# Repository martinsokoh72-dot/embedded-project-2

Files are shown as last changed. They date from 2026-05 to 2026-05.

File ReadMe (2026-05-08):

STM32L432 Advanced PC Fan Speed Controller with Overspeed Alarm
Author: Martins Osemudiamen Okoh
TU Dublin ID: A00047170
Course: Embedded Systems Project – EENG1030

Project Description
This embedded system project implements a real-time, closed-loop motor speed monitoring and control system using an STM32L432KC microcontroller. The system reads rotational speed from a quadrature encoder for user input and a tachometer for fan feedback. It controls the fan speed via PWM output, provides visual feedback using an LED, and activates an audible buzzer alarm when the fan exceeds a safe speed threshold of 3500 RPM. A serial debug interface and an SPI display provide real-time status information.

The video showcase of this project can be viewed via: https://youtu.be/aQIbt7y0xQ4?si=APt8LlkEA8uwMtla
A techncial report for this project can be found in this repository: /Technical Report.pdf
The schematic design was performed using KIcad in this repository: /embeeded_project_design.kicad_sch
The main source code file for this project can be found in this repository directory: /source code/src/main.c

Aim & Objectives
Aim: Design and implementation of an advanced PC fan speed controller using an STM32L432KC microcontroller with an overspeed alarm.

Objectives:

1) Schematic design of the PC fan speed controller.
2) Software implementation.
3) Hardware implementation.
4) Testing / Debugging (software and hardware).
5) Documentation.

Hardware Requirements
Components List
1) STM32L432KC microcontroller board (e.g., Nucleo-L432KC)
2) 12V PC Fan with 4-wire connection (PWM control & Tachometer output)
3) Quadrature rotary encoder
4) 1.8" TFT SPI LCD (ST7735S)
5) LED (visual status indicator)
6) Buzzer (audible alarm)
7) Push button (for tachometer input)
8) 330 Ohm resistor
9) Breadboard and connecting wires
10) 12V DC Bench Power Supply
11) USB-to-UART converter / USB Cable (for serial debugging)

System Pin Connections
    Component	        Signal	              STM32L432 Pin	Function
1)  Rotary Encoder      CLK	                  PA0	TIM2_CH1 (Encoder Input)
                        DT	                  PB3	TIM2_CH2 (Encoder Input)
                        VCC                   3.3V	Power
                        GND	                  GND	Ground
    
2)  PC Fan	            PWM (Blue)	          PA6	TIM16_CH1 (Speed Control)
                        Tachometer (Green)	  PB4	EXTI4 (Speed Feedback)
                        GND (Black)	          GND	Ground
                        +12V (Yellow)	        12V Supply	Power
    
3)  LED Indicator	    Anode	                PB5	Overspeed Status
                        Cathode	              GND (via 330Ω)	
    
4)  Buzzer	            Positive	            PB6	Audible Alarm
                        Negative	            GND	
    
5)  LCD Screen (SPI)    LCD	                  3.3v
                        SCL	                  PA5	SPI1_SCK
                        SDA	                  PA7	SPI1_MOSI
                        CS	                  PA4	Chip Select
                        RESET	                PB0	Reset
                        DC	                  PB1	Data/Command
                        VCC	                  3.3V	Power
                        GND	                  GND	Ground
    
6)  Serial Debug	    TX	                  PA2	USART2_TX
                        RX	                  PA15	USART2_RX

Features
1) Encoder-based Speed Control: A quadrature encoder connected to TIM2 (Mode 3) provides precise user input for setting the fan speed.
2) PWM Generation: Timer 16 produces a 25 kHz PWM signal on PA6, with a duty cycle adjustable from 0% to 100% based on the encoder position.
3) Tachometer Speed Calculation: Measures actual fan RPM by counting tachometer pulses (2 pulses/rev) on PB4 over a 0.1333-second interval.
4) Overspeed Detection & Alarm: Triggers an audiovisual alarm when the RPM exceeds 3500.
5) Visual Alarm: LED (PB5) turns OFF (normally ON when speed is safe).
6) Audible Alarm: Buzzer (PB6) generates a 500 Hz square wave.
7) Real-Time Monitoring: Outputs encoder value, PWM duty, and RPM to a serial console for debugging.
8) SPI Display: Shows current encoder position and fan RPM on a 1.8" TFT LCD.

        Key System Parameters
    Parameter	                      Value
1)  System Clock	                  80 MHz
2)  PWM Frequency	                  25 kHz
3)  PWM Resolution	                  3200 steps (ARR = 3199)
4)  Encoder Count Range	              0 - 159 (ARR = 159)
5)  RPM Safe Threshold	              3500 RPM
6)  Buzzer Tone Frequency	          500 Hz
7)  Buzzer Timer Interrupt Rate	      1000 Hz (1 ms)
8)  Main Loop Update Rate	          10 Hz (100 ms delay)

Register Configuration Summary
Timer 2 (Encoder)
1) Mode: Quadrature encoder mode 3 (counts on both edges of TI1 and TI2)
2) Auto-reload (ARR): 159 (0-159 count range)
3) Inputs: PA0 (TI1) and PB3 (TI2) as capture inputs (Alternate Function 1)

Timer 16 (PWM for Fan Speed)
1) Prescaler (PSC): 0
2) Auto-reload (ARR): 3199 (results in 80 MHz / 3200 = 25 kHz)
3) Pulse (CCR1): 1600 (default 50% duty cycle)
4) Output: PA6 (Alternate Function 14)
5) Break and Dead-Time (BDTR): MOE bit set (required for PWM output)

Timer 6 (Buzzer Tone)
1) Prescaler (PSC): 7999 (divides 80 MHz to 10 kHz)
2) Auto-reload (ARR): 9 (results in 10 kHz / 10 = 1 kHz update events)
3) Interrupt: Toggles PB6 on each interrupt, producing a 500 Hz square wave when active.

External Interrupt (EXTI4 for Tachometer)
1) Pin: PB4
2) Trigger: Falling edge
3) Action: Increments pulse_count variable on each fan pulse (2 pulses/rev)

Software Structure & Operation
Main Loop (10 Hz Update Rate)
Read encoder counter (TIM2->CNT) as the desired speed position.
Scale the encoder value (0-159) to a PWM duty cycle (0-3199) and update TIM16->CCR1.
Safely copy the interrupt-driven pulse_count (with interrupts temporarily disabled).

Calculate speed in Hz and RPM:
speed_hz = pulse_count / pulse_per_rev (pulse_per_rev = 2)
speed_rpm = speed_hz × 450 (The factor 450 is derived from a 0.1333s measurement interval: 60 / 0.1333 = 450).

Check overspeed condition:
If RPM <= 3500: Turn LED ON, set playing = 0 (buzzer off).
If RPM > 3500: Turn LED OFF, set playing = 1 (buzzer on).

Output status string via serial (Encoder, PWM, RPM, Buzzer State).
Update SPI display with current encoder position and RPM.
Delay for 100 ms and repeat.

Interrupt Handlers
TIM6_DAC_IRQHandler: Runs at 1 kHz. If playing == 1, toggles PB6 to generate a 500 Hz tone. If playing == 0, ensures PB6 is LOW.

EXTI4_IRQHandler: Runs on every falling edge from the fan's tachometer pin (PB4). Increments the volatile pulse_count variable.

Building and Flashing
Prerequisites
ARM GCC toolchain (arm-none-eabi-gcc)
STM32CubeProgrammer or OpenOCD
ST-Link debugger (built into Nucleo boards)

Setup & Build Instructions
Clone the repository and navigate to the project directory.
Connect the STM32L432 Nucleo board to your PC via USB.
Run make to build the project and generate the binary file.
Run make flash to program the binary onto the microcontroller using ST-Link.

Serial Output Examples
Initialization Verification:

MODER PA6: 2
AFR PA6: 14
TIM16 CR1: 129
TIM16 CCER: 1
TIM16 BDTR: 32768
TIM16 ARR: 3199
TIM16 CCR1: 1600
Runtime Monitoring:

ENC: 45, CCR1: 905, RPM: 1250, buzz: 0
ENC: 78, CCR1: 1568, RPM: 2150, buzz: 0
ENC: 120, CCR1: 2415, RPM: 3300, buzz: 0
ENC: 155, CCR1: 3118, RPM: 4250, buzz: 1   ← Overspeed!

Troubleshooting
Symptom	Likely Cause	Fix
No PWM output	MOE bit not set in TIM16 BDTR	Ensure TIM16->BDTR = 0x8000 in initTimer16().
Encoder not counting	Wrong alternate function for pins	Verify PA0 and PB3 are configured as Alternate Function 1 (AF1).
Buzzer always silent	TIM6 interrupt disabled	Check NVIC ISER1 bit 22 (IRQ 54) is enabled.
LED always off	Constant overspeed condition or GPIO error	Verify the speed_rpm calculation and PB5 mode.
Fan not spinning at 100%	PWM frequency mismatch	Ensure TIM16 ARR=3199 for 25kHz, as required by the 4-wire fan spec.
Display blank	SPI initialization failure or power	Check display power (3.3V) and SPI connections (PA5, PA7, PA4, etc.).

Safety Notes
Hearing Protection: The buzzer produces a 500 Hz tone at full volume during overspeed. Avoid prolonged exposure during testing.

Voltages: The system uses a 12V supply for the fan. Ensure all connections are secure to prevent short circuits.

Fan Safety: Keep objects away from the fan blades while the system is powered.

Current Limits: The LED is current-limited by a 330Ω resistor. Do not connect the LED without a current-limiting resistor.

Files in Project
File	Description
main.c	Main program, peripheral initialization, and main loop.
display.h/c	SPI display driver for the ST7735S LCD.
eeng1030_lib.h	Course library with utilities for GPIO, delays, serial, etc.
Makefile	Build configuration for the ARM GCC toolchain.

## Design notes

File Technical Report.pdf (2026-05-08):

# Technical Report

# Embedded System Project: Advanced PC FAN speed controller with over-speed alarm. Author: Martins Osemudiamen

# Okoh. TU Dublin ID: A00047170

Table of Content I. AIm | 1 II. Objective | 1 III. Design | 1 IV. Components | 2 V. Software Code | 9 VI. Testing | 20 VII. Conlusion | 24 VIII. Reference | 25

Table of Table

I. Table 1: STM32L432KC | 2
II. Table 2: PIN connection | 2
III. Table 3: Button | 3
IV. Table 4: LED | 3
V. Table 5: Resistor | 3
VI. Table 6: Rotary Encoder | 4
VII. Table 7: PIN connection | 4
VIII. Table 8: LCD Screen | 5
IX. Table 9: PIN connection | 5
X. Table 10: Buzzer | 5
XI. Table 11: PC FAN | 6
XII. Table 12: 4-wire PinOut | 6
XIII. Table 13: USB Cable | 7
XIV. Table 14: Breadboard | 7
XV. Table 15: Connecting wires | 7
XVI. Table 16: Power Supply | 8
Tables of Figures
I. Figure 1: Ciricuit Design of PC fan controller using KICad 10.0. | 1
II. Figure 2: Declaration of functions and addition of necessary files and libraries. | 9
III. Figure 3: Declaration of global variables. | 9
IV. Figure 4: Main function of the software implementation part 1. | 10
V. Figure 5: Main function of the software implementation part 2. | 11
VI. Figure 6: Main function of the software implementation part 3. | 11
VII. Figure 7: Main function of the software implementation part 4. | 12
VIII. Figure 8: Setup Function. | 13
IX. Figure 9: delay , Pull Up resistor and Pinmode. | 14
X. Figure 10: Timer 2. | 15
XI. Figure 11: Timer 16. | 16
XII. Figure 12: Timer 6. | 16
XIII. Figure 13: Timer 6 interrupt . | 17
XIV. Figure 14: Function of installing delay. | 17
XV. Figure 15: Function to enable pull-up resistor. | 17
XVI. Figure 16: Function for PIN mode selection. | 18
XVII. Figure 17: Function for initializing clock. | 18
XVIII. Figure 18: Function of initializing serial communication and pin definition. | 18
XIX. Figure 19: Function for writing via serial communication. | 19
XX. Figure 20: Function for write via serial communication to terminal display. | 19
XXI. Figure 21: Function to handle interrupt to counting the speed pulse. | 19
XXII.Figure 22: Function for milliseconds counting and delays. | 19
XXIII. Figure 23: Hardware implementation of bread board. | 20
XXIV. Figure 24: Power supply. | 21
XXV. Figure 25: Output result 1 on terminal. | 21
XXVI. Figure 26: Output result 2 on terminal. | 21
XXVII. Figure 27: Fan output speed signal 1 viewed on oscilloscope. | 22
XXVIII. Figure 28: PC fan Assemble with LED ON and Screen. | 22
XXIX. Figure 29: Output result 2 on terminal. | 23
XXX.Figure 30: Fan output speed signal 2 viewed on oscilloscope. | 23
XXXI. Figure 31: PC fan Assemble with LED OFF, Buzzer toggling and Screen . | 24

Aim: Design and implementation of a Advanced PC fan speed controller using STM32L432KC microcontroller with overspeed alarm. Objective:

1. Schematic design of the PC fan speed controller. 2. Software implementation. 3. Hardware implementation. 4. Testing / Debugging. 5. Documentation. Design:

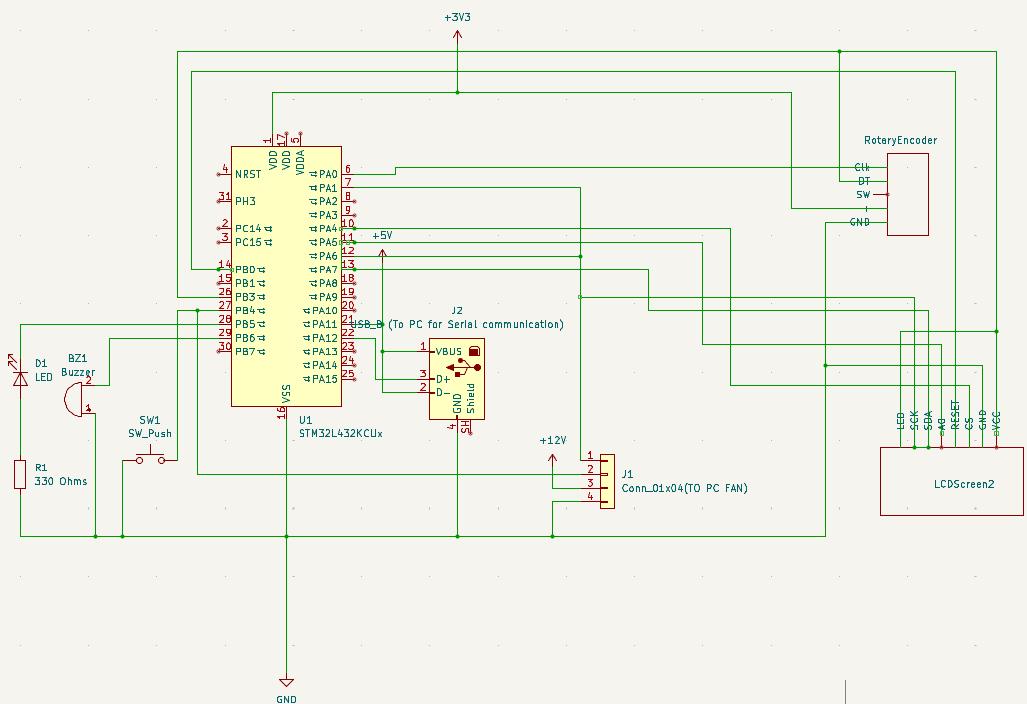
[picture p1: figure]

Figure 1: Ciricuit Design of PC fan controller using KICad 10.0.

In the Figure 1 above, the design comprises of STM32L432KC microcontroller, a push button, an LED,330 Ohms resistor, Rotary Encoder, LCD Screen, Buzzer, PC fan 4 wire connector, a

USB cable component for serial communication, voltage supplies of 3.3 and 12 voltages, connecting wires, breadboard and a ground.

Components:

1) STM32L432KC Microcontroller:

Table 1: STM32L432KC
Specification | Detail
Manufacturer | STMicroelectronics
Core | ARM Cortex-M4F (with FPU)
Max frequency | 80 MHz
Flash memory | 256 KB
SRAM | 64 KB
Operating voltage | 1.71V – 3.6V
Package | 32-pin QFN
Key peripherals | GPIO, TIM2, TIM6, TIM16, USART, SPI, EXTI, NVIC

Component Role: Central processing unit. Runs the main control loop, reads encoder and push button inputs, generates PWM for the fan, controls the LED and buzzer, communicates with the LCD via SPI, and outputs debug data over USB serial. It also serve as a 3.3 volt power supply for the circuit [1). Connection: The Pin connection is as in Table 2. Table 2: PIN connection

Pin | Direction | Function
PA0 | Input | TIM2_CH1 – Encoder CLK (AF1)
PA2 | Output | USART2_TX – Serial transmit (AF7)
PA5 | Output | SPI1_SCK – Display clock
PA6 | Output | TIM16_CH1 – PWM fan control (AF14)
PA7 | Output | SPI1_MOSI – Display data
PA15 | Input | USART2_RX – Serial receive (AF3)
PB3 | Input | TIM2_CH2 – Encoder DT (AF1)
PB4 | Input | EXTI4 – Tachometer pulse input (falling edge)
PB5 | Output | GPIO – LED overspeed indicator
PB6 | Output | GPIO – Buzzer tone output (toggled by TIM6)

All peripherals are clocked through the internal PLL configured to 80 MHz at startup in initClocks(). SysTick is configured to interrupt every 1 ms to provide the delay_ms() timebase [2].

2) Push Down Button:
Table 3: Button
Specification | Detail
Type | Tactile momentary switch
Number of pins | 2 connected internally
Actuation Force | 100 - 300gf
Contact resistance | < 100 mΩ
Operating life | 10,000 – 100,000 cycles

Component Role: Provides user input for controlling the system (e.g., starting/stopping the fan, resetting the system, or toggling display modes). In this project, it may serve as the tachometer pulse input or a manual override switch [3]. Connection: Connected to PB4 with internal pull-up enabled. When pressed, the pin reads

LOW (0V); when released, pull-up keeps it HIGH (3.3V). Falling edge triggers an external interrupt. 3) Light Emitting Diode (LED) :

Table 4: LED
Specification | Detail
Type | Standard 5mm or SMD LED
Color | Green
Forward voltage (Vf) | 2.8V – 3.2V (green)
Forward current (If) | 10 – 20 mA
Viewing angle | 1000 – 5000 mcd 30° – 60° Luminous intensity

Component Role: Visual status indicator. Illuminates when the fan speed is within safe limits (≤ 3500 RPM) and turns off during over speed conditions [4]. Connection: Anode connected to PB5 through a 330Ω current-limiting resistor; cathode

connected to ground. 4) 330 Ohm resistor:

Table 5: Resistor
Specification | Detail
Resistance | 330 Ω ±5%
Power rating | 0.25W (1/4W)
Type | Carbon film or metal film
Color code | Orange – Orange – Brown – Gold

Component Role: Current-limiting resistor for the LED. 330Ω provides approximately 4 mA current, ensuring safe operation without exceeding the LED's maximum rating or the microcontroller's GPIO current limit (20 mA per pin) [5]. Connection: Placed in series between PB5 (microcontroller output) and the LED anode.

5) Rotary Encoder:

Table 6: Rotary Encoder
Specification | Detail
Type | Incremental quadrature encoder
Pulses per revolution (PPR) | 2 (as defined in code: #define pulse_per_rev 2)
Output signals | Channel A (CLK), Channel B (DT)
Output type | Open-collector or push-pull
Supply voltage | 3.3V – 5V
Mechanical life | 30,000 – 100,000 cycles
Encoder Count Range | 0 – 159 (set by TIM2 ARR = 159 in code)

Component Role: Provides the primary user input for fan speed control. As the knob is rotated clockwise or counter-clockwise, it generates two out-of-phase square wave signals (CLK and DT) which TIM2 decodes in hardware encoder mode 3 (quadrature). The resulting count value in TIM2->CNT (ranging 0–159) is read in the main loop and scaled to a PWM duty cycle on TIM16, directly controlling fan speed. Rotating fully clockwise produces maximum PWM (100% duty), and fully counter-clockwise produces minimum (0%) [6]. Connection: The Pin connection is as in Table 2. Table 7: PIN connection

Encoder Pin | STM32L432 Pin
CLK | PA0
DT | PB3
VCC | 3.3v
GND | GND
SW | - How it works: PA0 and PB3 are configured in alternate function mode (AF1) to route directly

into TIM2's hardware encoder interface. TIM2 is configured in encoder mode 3 (TIM2- >SMCR = 3), meaning both edges of both channels are counted, giving smooth and accurate

position tracking. The counter wraps between 0 and 159 as set by TIM2->ARR = 159. No software debouncing is required as the hardware timer filters signal noise inherently. Internal pull-ups are not explicitly set for PA0/PB3 as the encoder module typically includes its own pull-up resistors on CLK and DT.

6) LCD Screen (SPI Interface)

Table 8: LCD Screen
Specification | Detail
Type | 1.8" TFT SPI LCD v1.1
Resolution | 128 × 160 pixels
Display Driver IC | ST7735S
Interface | SPI (Serial Peripheral Interface)
Operating voltage | 3.3V
Colour Depth | 16-bit (65,536 colours)
Viewable Area | 1.8 inches diagonal
Pixel Format | RGB565

Component Role: Provides a real-time visual readout of system state to the user. In this project, it displays the current rotary encoder position (pos) and the calculated fan speed (RPM). Text is rendered using printText() and screen regions are cleared between updates using fillRectangle() to prevent display artefacts. Colour coding is used to distinguish data fields — yellow for encoder position, green for RPM [7]. Connection: The Pin connection is as in Table 9. Table 9: PIN connection

Display Pin | STM32L432 Pin
VCC | 3.3v
GND | GND
SCL | PA5
SDA | PA7
RESET | PB0
DC | PB1
CS | PA4
LED | 3.3v

7 ) Buzzer:
Table 10: Buzzer
Specification | Detail
Type | Piezoelectric transducer
Resonant frequency | 500 Hz (typical)
Operating voltage | 3V – 12V
Current consumption | 5 – 15 mA
Sound pressure level | 75 – 85 dB at 10 cm

Component Role: Audible alarm. Activates when the fan speed exceeds 3500 RPM, producing a 500 Hz tone to alert the user of an overspeed condition [8].

Connection: Positive (+) to PB6 (microcontroller output) and Negative (-) to Ground

Drive method: Timer 6 generates a 1000 Hz interrupt that toggles PB6 at 500 Hz when playing = 1, creating a square wave. The buzzer produces sound due to the piezoelectric element vibrating at this frequency . Behavior:

Speed ≤ 3500 RPM: playing = 0 via PB6 LOW I.e silent
Speed > 3500 RPM: playing = 1 via PB6 toggles at 500 Hz I.e audible tone
7) PC FAN with 4-wire connection:

Table 11: PC FAN
Specification | Detail
Type | Brushless DC fan (computer cooling fan)
Wire colors (standard) | Black (GND), Yellow (12V), Green (Tachometer), Blue (PWM control)
Supply voltage | 12V DC
Current draw | 0.1A – 0.5A (typical)
Speed range | 0 – 4000+ RPM

Table 12: 4-wire PinOut
Wire Color | Signal | Function
Black | GND | Ground (0V)
Yellow | +12V | Power supply (12V)
Green | Tachometer | Open-collector output (2 pulses per revolution)
Blue | PWM | Speed control input (25 kHz, 0–100% duty cycle)

Component Role: The main actuator being controlled and monitored. The microcontroller sends a PWM signal to the blue wire to regulate fan speed, and reads tachometer pulses from the green wire to measure actual RPM [9]. Connection:Black (GND) to Common ground, Yellow (12V) to External 12V power supply, Green (Tachometer) to PB4 (EXTI4 interrupt input) – counts speed pulses and Blue (PWM) to

PA6 (TIM16 CH1) – receives 25 kHz PWM signal. How speed is measured: The fan's tachometer output produces 2 pulses per revolution

(open-collector). Each falling edge on PB4 triggers an interrupt, incrementing pulse_count. The main loop calculates speed every 0.1333 seconds. How speed is controlled: The PWM duty cycle on PA6 determines fan speed. The encoder

value (0–159) is scaled to set TIM16->CCR1 (0–3199). Duty cycle range: 0% (fan off) to 100% (maximum speed).

8) USB Cable (serial communication):

Table 13: USB Cable
Specification | Detail
Type | USB C
Length | 0.5m – 1m (typical)
Interface | USB 2.0 full-speed
Purpose | Provides serial communication between STM32 and PC

Component Role: Enables real-time monitoring and debugging. The STM32L432's USART peripheral is connected to the USB port via an onboard USB-to-serial converter (on Nucleo boards or external FTDI adapter). The PC receives debug messages at 9600 baud using a serial terminal (PuTTY, screen, minicom) [10]. Data transmitted are Initialization verification (register values) and Runtime status (encoder value, PWM duty, RPM, buzzer state). Connection: USB cable connects the microcontroller board to a computer. The computer's

serial monitor displays the debug output. 9) Breadboard:

Table 14: Breadboard
Specification | Detail
Type | Solderless breadboard
Size | 400 – 830 tie points (typical)
Contact material | Nickel-plated or tin-plated phosphor bronze
Pitch | 2.54mm (0.1 inch)

Component Role: Prototyping platform for assembling the circuit without soldering. Components and wires are inserted into the breadboard's contact holes, which are

electrically connected in rows and columns. The ground row is used as neural ground connections [11]. 10) Connecting wires:

Table 15: Connecting wires
Specification | Detail
Type | Jumper wires
Gauge | 22 AWG – 26 AWG
Length | 10 cm – 30 cm
Connector type | Dupont (2.54mm pitch)

Component Role: Establish all electrical connections between components on the breadboard [12].

Typical connections include:

i. Microcontroller pins to breadboard power rails
ii. Encoder to microcontroller pins (PA0, PB3, VCC, GND) iii. Push button to PB4 and ground
iv. LED and resistor to PB5 and ground
v. Buzzer to PB6 and ground
vi. LCD to SPI pins, VCC, and GND
vii. Fan tachometer (green) to PB4
viii. Fan PWM (blue) to PA6
ix. Fan ground (black) to common ground
x. Fan 12V (yellow) to 12V supply
xi. 3.3V and GND to breadboard power rails
11) Power Supply:

Table 16: Power Supply
Specification | Detail
Type | Regulated DC Bench Power Supply
Output Voltage | 0 – 30V DC (adjustable)
Output Current | 0 – 5A (adjustable limit)
Input Voltage | 220–240V AC, 50Hz
Output Terminals | Positive (+), Negative (−), Ground (GND)
Accuracy | ±(0.5% to 1%) depending on model
Ripple/Noise | Typically < 10mV

Component Role: The positive terminal (+12V) of the power supply is connected to the fan’s power input wire, while the negative terminal (GND) is connected to the fan ground wire I.e +terminal to Fan VCC (12v) and -terminal to GND [13].

Source Code:

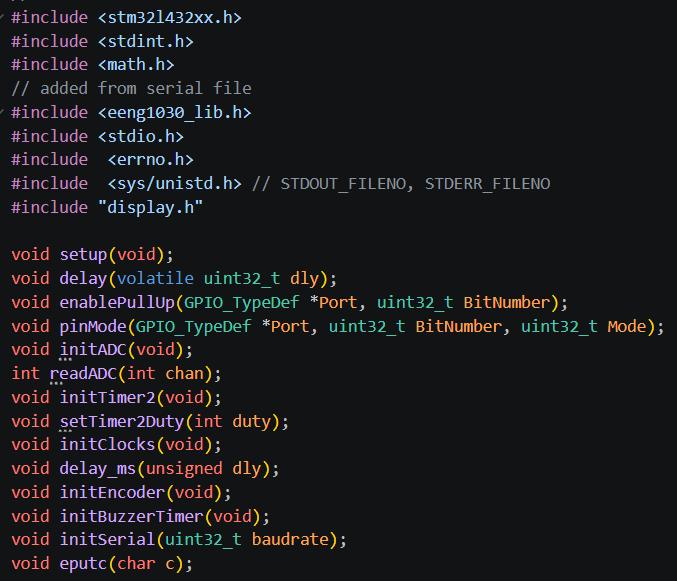
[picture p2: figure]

Figure 2: Declaration of functions and addition of necessary files and libraries. Figure 2 above shows a hardware initialization and utility library for an STM32L432xx

microcontroller (ARM Cortex-M4). It provides core functions for peripheral control, timing, analog reading, PWM generation, encoder interfacing, buzzer control, and serial

communication. The code appears to be part of a larger embedded systems project (likely for a robotics or mechatronics course, given the eeng1030_lib.h reference).

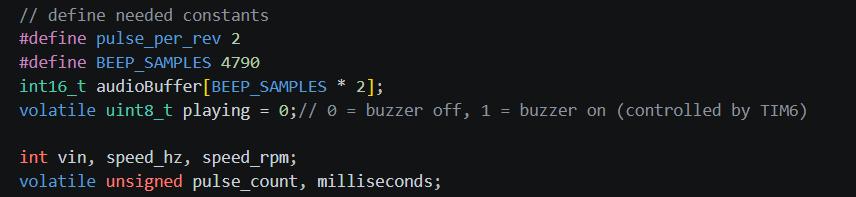
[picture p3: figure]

Figure 3: Declaration of global variables. Figure 3 above shows the constants and variables for motor speed sensing and buzzer audio

playback on an STM32 microcontroller. The constant pulse_per_rev is set to 2, meaning the motor encoder generates two pulses per revolution, while BEEP_SAMPLES defines the audio buffer size as 4790 samples. An int16_t array called audioBuffer allocates twice that many elements (9580 total) to store audio data for buzzer tones, and a volatile uint8_t flag named playing tracks whether the buzzer is active (1) or off (0), with updates controlled by Timer 6 interrupts. Integer variables vin, speed_hz, and speed_rpm hold motor voltage input and speed values in hertz and RPM respectively. Finally, two volatile unsigned variables— pulse_count for counting encoder pulses and milliseconds for system timing—are declared volatile because they are modified inside interrupt service routines but accessed in the main program loop.

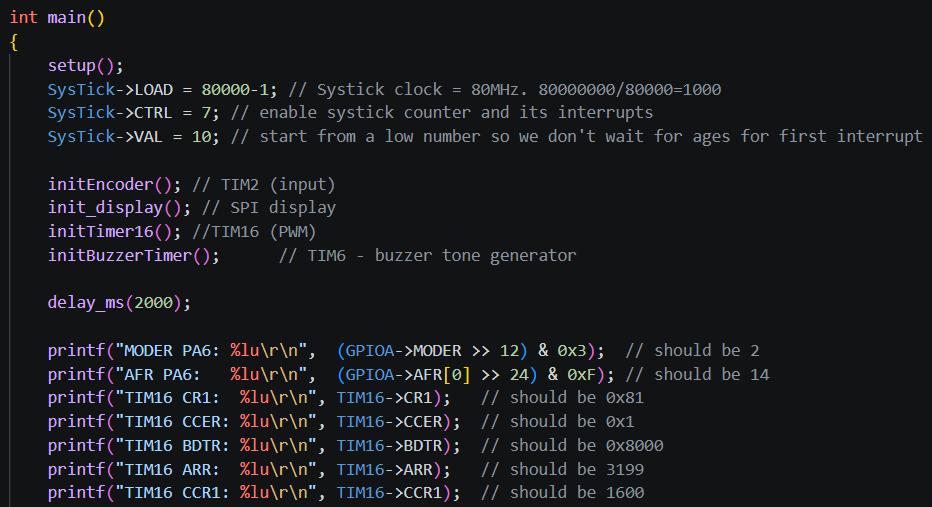
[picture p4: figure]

Figure 4: Main function of the software implementation part 1. This main() function in Figure 4 above initializes the entire embedded system and then

verifies the configuration by printing register values. It begins by calling setup() for basic hardware initialization, then configures the SysTick timer to generate interrupts every 1 millisecond (since an 80 MHz clock with a load value of 80,000 produces exactly 1000 Hz). It initializes the encoder on Timer 2, an SPI display, Timer 16 for PWM output, and Timer 6 for buzzer tone generation. After a 2-second delay to allow everything to stabilize, it prints the current register values for GPIO pin PA6 (checking its mode and alternate function), followed by several Timer 16 registers including CR1 (control), CCER (capture/compare enable), BDTR (break and dead-time), ARR (auto-reload value), and CCR1 (capture/compare value). These print statements serve as diagnostic checks to confirm that Timer 16 was configured correctly—for example, the ARR should be 3199 and CCR1 should be 1600, indicating a 50% duty cycle on the PWM output.

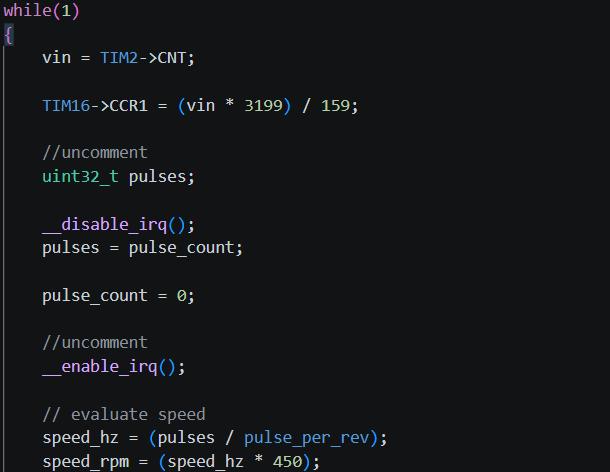
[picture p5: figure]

Figure 5: Main function of the software implementation part 2. Figure 5 above shows continuous loop reads the motor's input voltage from Timer 2's

counter register, scales it by a factor of 3199/159 (approximately 20.12) and writes the result to Timer 16's capture compare register to control a PWM output—likely for motor speed or LED brightness. It then safely copies the volatile pulse_count variable into a local pulses variable by disabling interrupts briefly to prevent corruption during the read, resets pulse_count to zero for the next measurement interval, and re-enables interrupts. Finally, it calculates the motor speed in hertz by dividing the accumulated pulses by pulse_per_rev (which is 2), then converts that to RPM by multiplying by 450—the conversion factor assumes the measurement period is 0.1333 seconds (since 60 seconds divided by 0.1333 equals 450). This loop continuously reads feedback, updates control outputs, and computes rotational speed in real time.

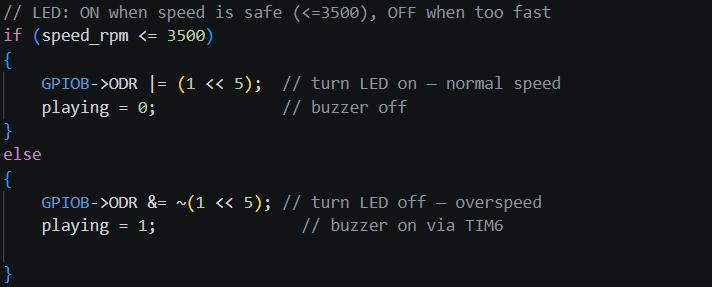
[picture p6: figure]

Figure 6: Main function of the software implementation part 3.

This code implemented in Figure 6 shows a safety monitoring system that controls an LED and buzzer based on motor speed. If speed_rpm is 3500 RPM or less (safe zone), it turns the LED on by setting bit 5 of GPIOB's output data register, and ensures the buzzer is off by setting playing = 0. If the speed exceeds 3500 RPM (overspeed condition), it turns the LED off by clearing bit 5, and activates the buzzer by setting playing = 1, which enables Timer 6 to generate an audible alarm tone. This provides both visual feedback (LED on/off) and audible warning (buzzer) to alert the user when the motor is running too fast.

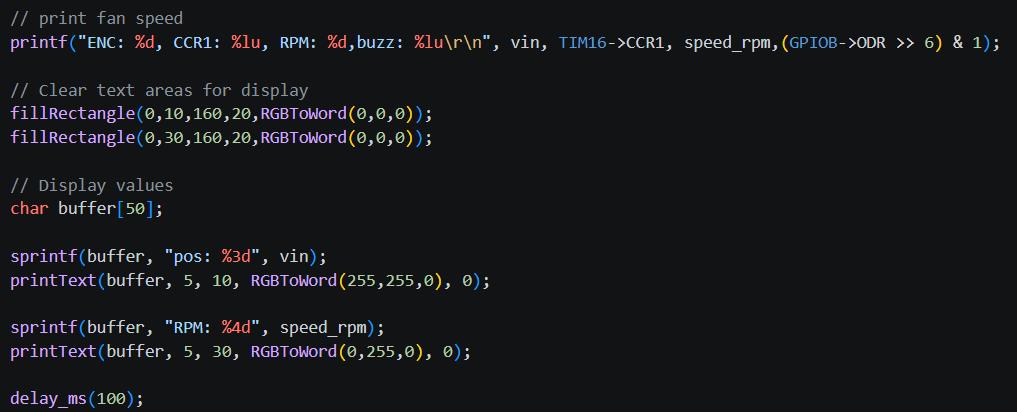
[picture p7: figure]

Figure 7: Main function of the software implementation part 4. This code in Figure 7 handles real-time data output and user interface updates. It first prints

a status line over serial containing the encoder value (vin), the current PWM capture compare register value from Timer 16, the calculated motor speed in RPM, and the buzzer state (extracted from bit 6 of GPIOB's output data register). It then updates an SPI display by clearing two text areas (at Y-positions 10 and 20, and 30 and 40) using black rectangles. The encoder position (vin) is formatted into a string labeled "pos" and displayed in yellow text at the top, while the RPM value is formatted and displayed in green text below. Finally, a 100 millisecond delay sets the loop's update rate to approximately 10 Hz, providing stable, readable updates without overwhelming the system.

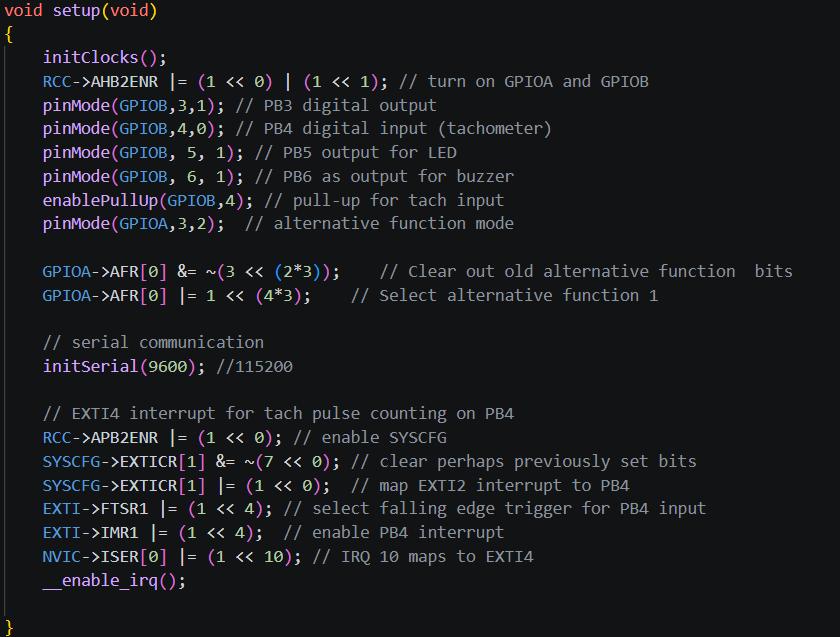
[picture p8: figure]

Figure 8: Setup Function. This setup() function shown in Figure 8 above performs all low-level hardware initialization

for the system. It starts by calling initClocks() to configure system clocks, then enables GPIO ports A and B via the AHB2ENR register. It configures several GPIO pins: PB3 as a digital output, PB4 as a digital input for tachometer sensing (with a pull-up enabled), PB5 as an output for the status LED, and PB6 as an output for the buzzer. Pin PA3 is set to alternative function mode, and its alternate function is configured to AF1 (likely for timer input capture). Serial communication is initialized at 9600 baud for debugging output. The function then

sets up an external interrupt on PB4 to count tachometer pulses: it enables the SYSCFG clock, configures the EXTI to map PB4 to interrupt line 4, selects falling edge triggering, enables the

interrupt in the EXTI controller, and enables the EXTI4 interrupt in the NVIC (IRQ 10). Finally, it globally enables interrupts with __enable_irq(), allowing the tachometer pulse counting to begin.

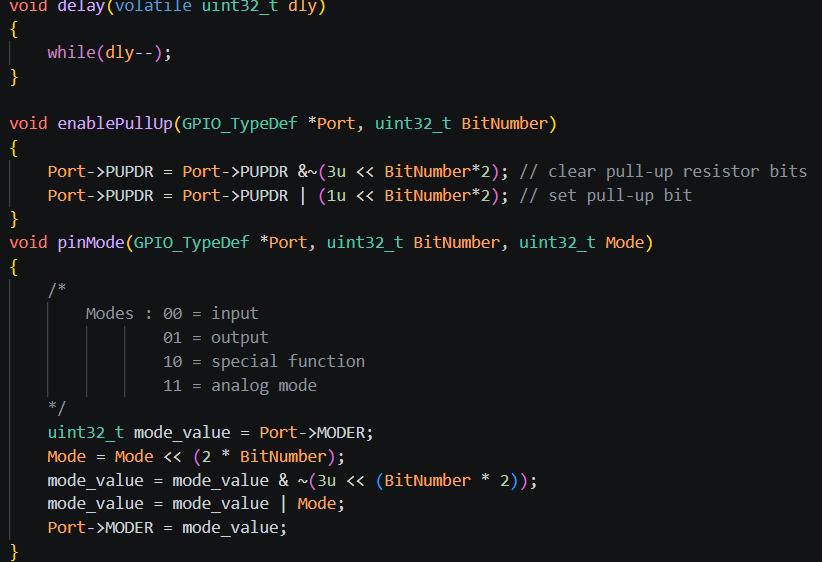
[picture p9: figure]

Figure 9: delay , Pull Up resistor and Pinmode. These three functions shown in Figure 9 above provide basic GPIO control and timing

utilities. delay(volatile uint32_t dly) creates a simple blocking delay by decrementing the input value

in a tight while loop until it reaches zero. The parameter is declared volatile to prevent the
compiler from optimizing away the loop. enablePullUp(GPIO_TypeDef | *Port, | uint32_t | BitNumber) | activates the internal pull-up

resistor on a specified GPIO pin. It clears the two bits controlling the pull configuration for that pin by ANDing with a mask, then sets the lower bit (binary 01) to select pull-up mode. pinMode(GPIO_TypeDef *Port, uint32_t BitNumber, uint32_t Mode) configures the mode of

a GPIO pin by writing to the port's MODER register. The Mode parameter (0=input, 1=output, 2=alternate function, 3=analog) is shifted left by twice the bit number to align with the two

bits that control that pin, then combined into the register after clearing the existing configuration bits for that pin.

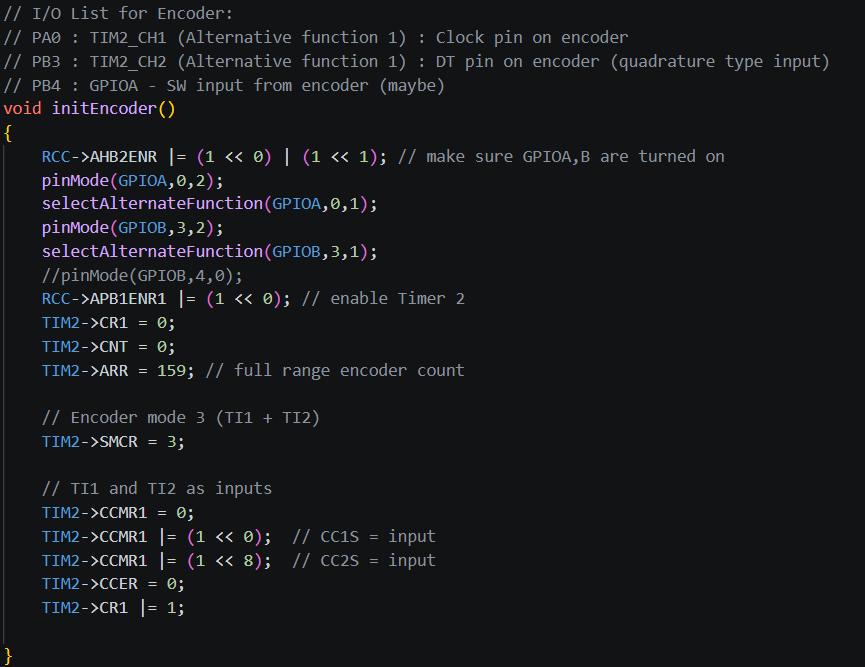
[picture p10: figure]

Figure 10: Timer 2. This initEncoder() function configures Timer 2 shown in Figure 10 above in encoder mode to

read a quadrature rotary encoder. It enables GPIOA and GPIOB clocks, then configures PA0 as TIM2 channel 1 (clock pin) and PB3 as TIM2 channel 2 (DT pin) both in alternate function mode with AF1 selected. Timer 2 is enabled, its counter is reset to zero, and the auto-reload register ARR is set to 159, which limits the count range from 0 to 159. The SMCR register is set to mode 3, which configures the timer to count on both TI1 and TI2 edges (quadrature decoding). The CCMR1 register sets both capture compare channels 1 and 2 as inputs, and CCER is cleared to configure the inputs. Finally, the timer is started by setting bit 0 in CR1. As the encoder rotates, the timer count automatically increments or decrements based on direction, and the value can be read from TIM2->CNT.

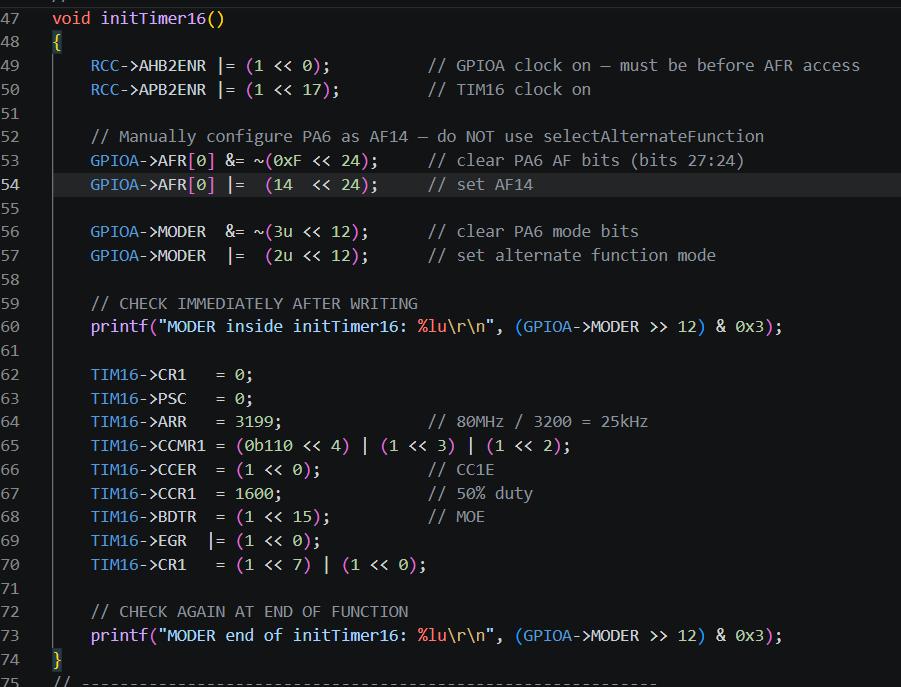
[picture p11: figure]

Figure 11: Timer 16. This initTimer16() function shown in Figure 11 configures Timer 16 to generate a PWM signal

on pin PA6. It enables the GPIOA clock and Timer 16 clock, then manually configures PA6 to use alternate function 14 (AF14), which is the timer output channel for TIM16. The pin mode is set to alternate function. Diagnostic printf statements verify the pin's mode register value immediately after configuration. The timer itself is then set up: prescaler is 0, the auto- reload register ARR is 3199, which with an 80 MHz clock produces a PWM frequency of 25

kHz. The CCMR1 register configures channel 1 for PWM mode 2 (110 binary) with preload enabled, and CCER enables the capture/compare output. CCR1 is set to 1600, giving a 50% duty cycle. The BDTR register's MOE (Main Output Enable) bit is set, which is required for advanced timers to enable PWM output. An update event generates reloads the settings, and CR1 enables auto-reload preload and starts the timer counter.

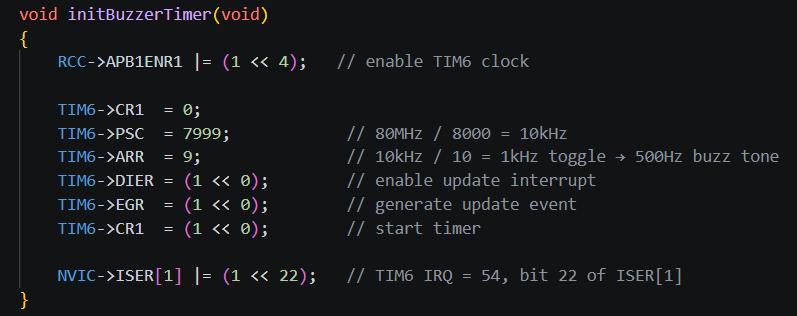
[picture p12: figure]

Figure 12: Timer 6.

This initBuzzerTimer() function shown in Figure 12 above configures Timer 6 to generate an interrupt for producing an audible buzzer tone. It enables the TIM6 clock via the APB1ENR1 register, then sets the prescaler to 7999, which divides the 80 MHz system clock down to 10 kHz. The auto-reload register ARR is set to 9, meaning the timer counts from 0 to 9 and then resets, creating an update event at 1 kHz (since 10 kHz divided by 10 equals 1000 Hz). This triggers an interrupt twice per cycle, allowing the buzzer pin to toggle at 500 Hz, which produces an audible 500 Hz tone. The DIER register enables the update interrupt, an update event is generated to load the prescaler and ARR values, and the timer is started by setting bit 0 in CR1. Finally, the interrupt is enabled in the NVIC at IRQ number 54 (bit 22 in ISER[1]), allowing the buzzer control to be handled in the TIM6 interrupt service routine.

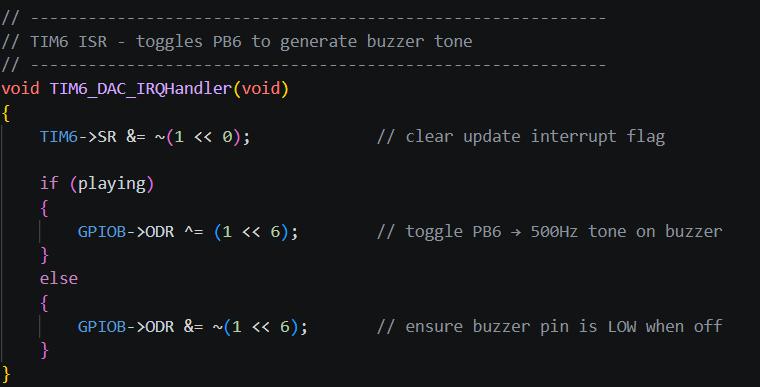
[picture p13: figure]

Figure 13: Timer 6 interrupt . This is the interrupt service routine for Timer 6 shown in Figure 13 which generates the

buzzer tone. When a timer update interrupt occurs, the handler first clears the interrupt flag by writing 0 to bit 0 of TIM6's status register (SR). It then checks the global playing flag: if playing is 1 (buzzer active), it toggles pin PB6 by XORing bit 6 of GPIOB's output data register, creating a square wave at 500 Hz and producing an audible tone. If playing is 0 (buzzer off), it ensures the buzzer pin is driven low by clearing bit 6, keeping the buzzer silent. This ISR runs at 1000 Hz (every 1 ms), toggling the pin on each interrupt to produce the 500

Hz tone only when the overspeed condition is active.

Figure 14: Function of installing delay.

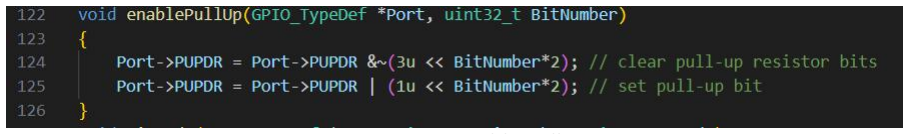
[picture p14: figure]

Figure 15: Function to enable pull-up resistor.

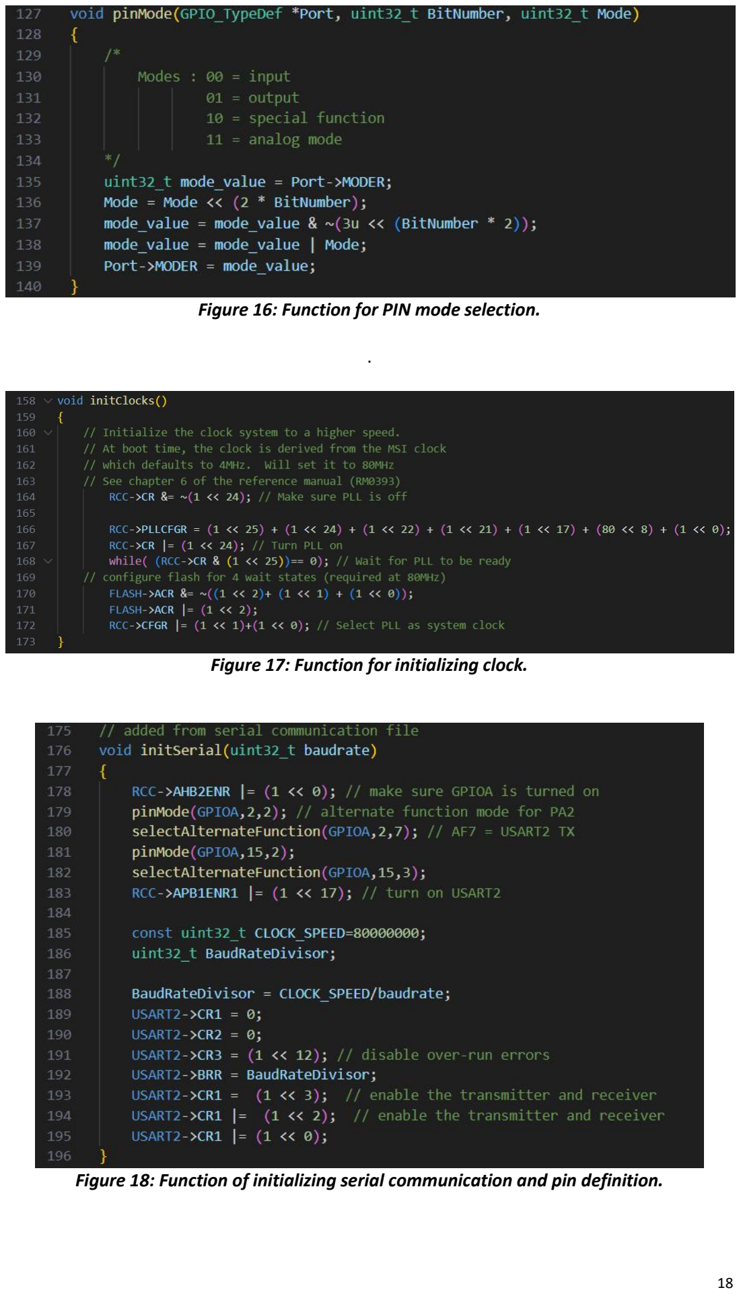
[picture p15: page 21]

Figure 16: Function for PIN mode selection.

Figure 17: Function for initializing clock.

Figure 18: Function of initializing serial communication and pin definition.

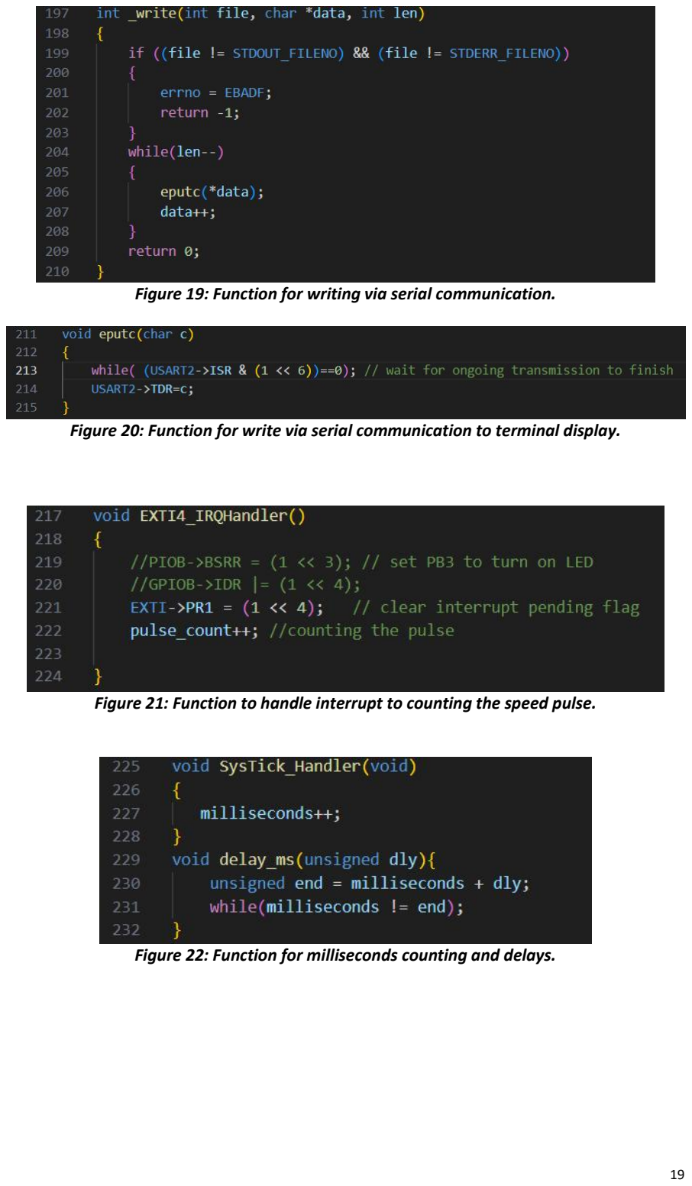
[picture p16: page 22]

Figure 19: Function for writing via serial communication.

Figure 20: Function for write via serial communication to terminal display.

Figure 21: Function to handle interrupt to counting the speed pulse.

Figure 22: Function for milliseconds counting and delays.

Testing:

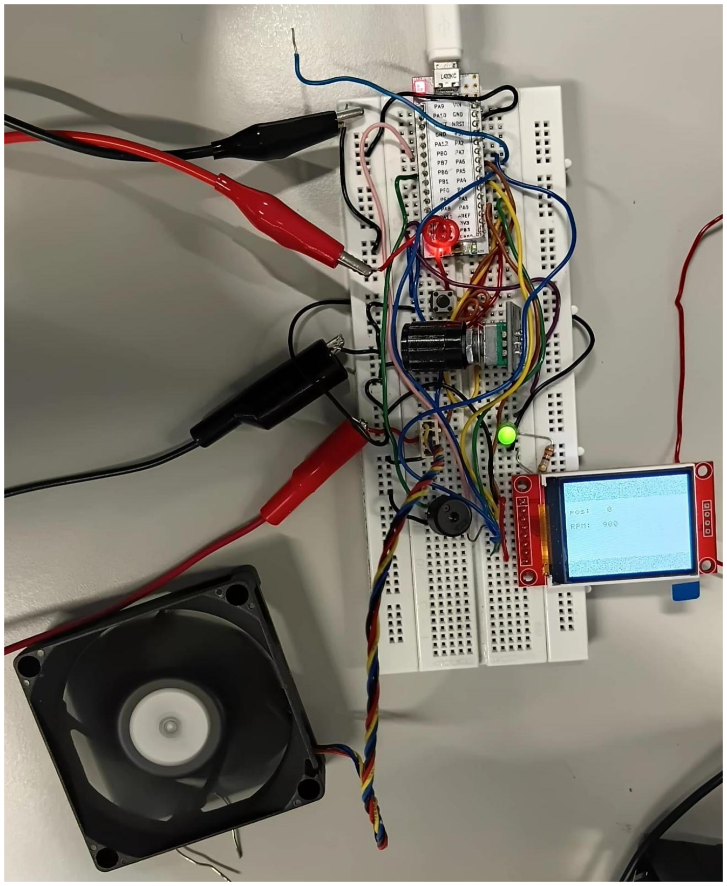
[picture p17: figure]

Figure 23: Hardware implementation of bread board. The whole assemble is shown above in Figure 23 where the PC fan controller is being

power,programmed and debugged.

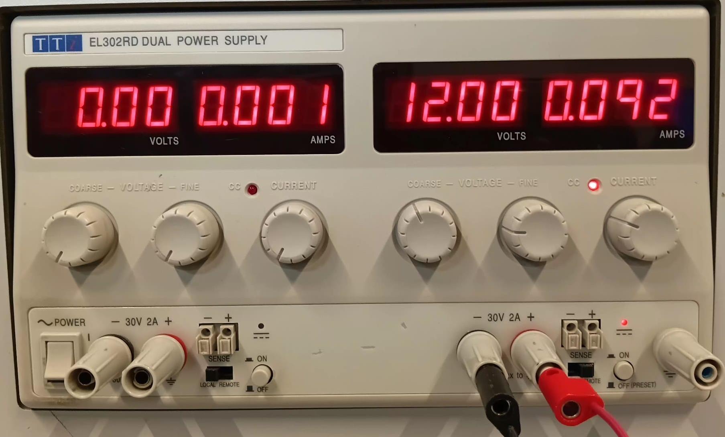
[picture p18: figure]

Figure 24: Power supply.

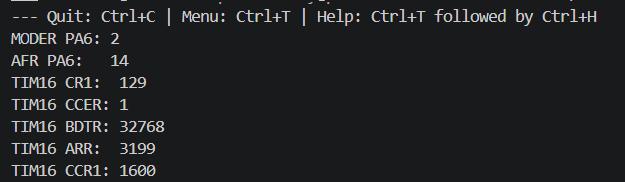
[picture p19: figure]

Figure 25: Output result 1 on terminal. The printed diagnostic values shown in Figure 25 confirm that Timer 16 and its associated

GPIO pin PA6 have been configured correctly for PWM output. PA6's mode register reads 2, indicating alternate function mode, and its alternate function register reads 14, which correctly maps to TIM16 channel 1. Timer 16's control register CR1 shows 129 (binary 10000001), meaning the counter is enabled with auto-reload preload activated. The capture/compare enable register CCER reads 1, confirming the output channel is enabled, while the break and dead-time register BDTR reads 32768 (binary 1000000000000000),

indicating the main output enable bit is set—a critical requirement for PWM output on advanced timers. Finally, the auto-reload register ARR contains 3199, producing a 25 kHz PWM signal from the 80 MHz clock, and the capture/compare register CCR1 contains 1600, giving a precise 50% duty cycle. All values match the expected configuration, confirming

TIM16 is fully operational and ready to generate PWM signals on pin PA6.

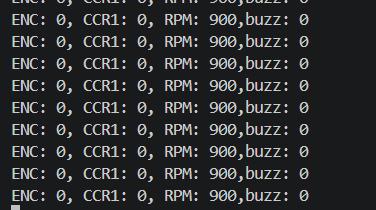
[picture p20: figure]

Figure 26: Output result 2 on terminal.

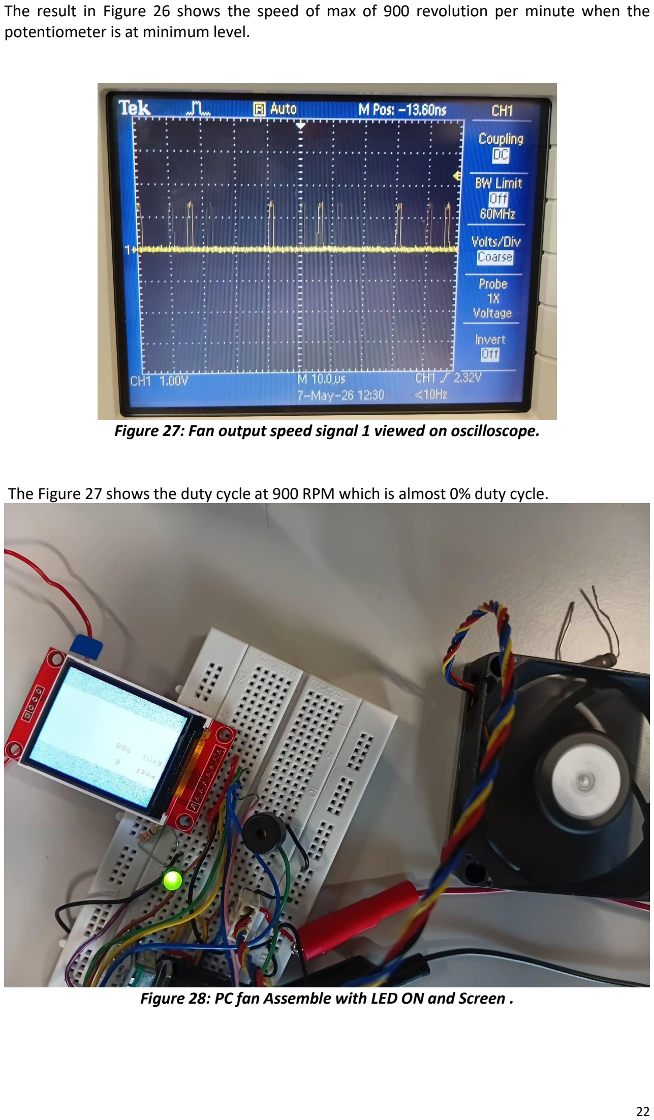
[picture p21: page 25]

The result in Figure 26 shows the speed of max of 900 revolution per minute when the potentiometer is at minimum level.

Figure 27: Fan output speed signal 1 viewed on oscilloscope. The Figure 27 shows the duty cycle at 900 RPM which is almost 0% duty cycle.

Figure 28: PC fan Assemble with LED ON and Screen .

The result in Figure 28 shows the output speed signal from the PC fan with LED ON, Fan ON and Screen indicating rotary position: 6 and speed 900 RPM.

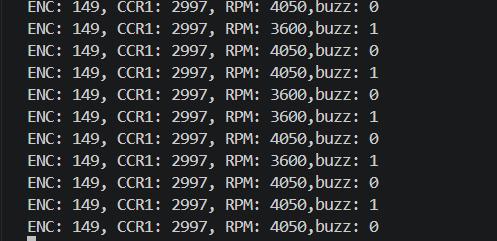
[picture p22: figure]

Figure 29: Output result 2 on terminal. The result in Figure 29 shows rotary postion:149 with speed minimum of 3600 and buzzer

toggling between 0 and 1.

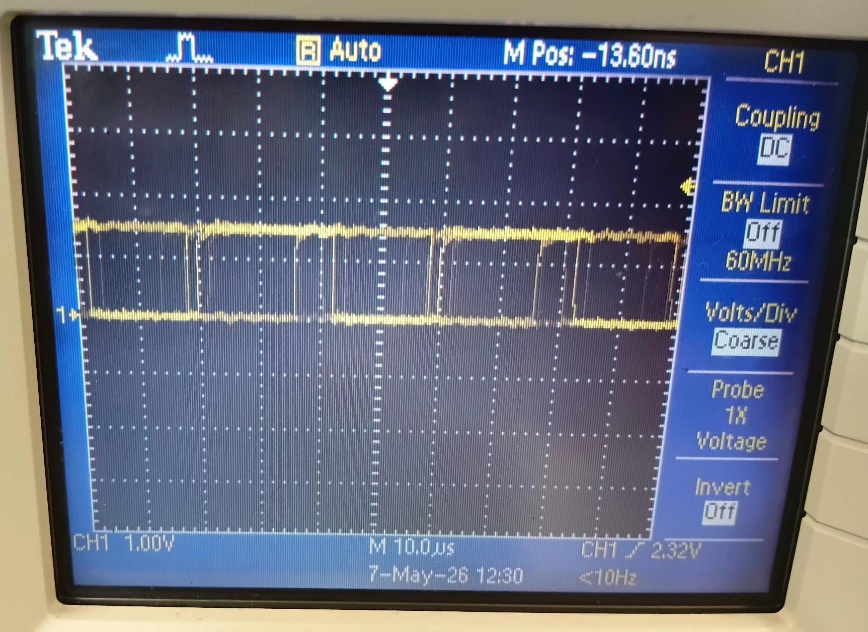
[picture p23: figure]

Figure 30: Fan output speed signal 2 viewed on oscilloscope. The Figure 30 shows the duty cycle at minimum 3600 RPM which is almost 100% duty cycle.

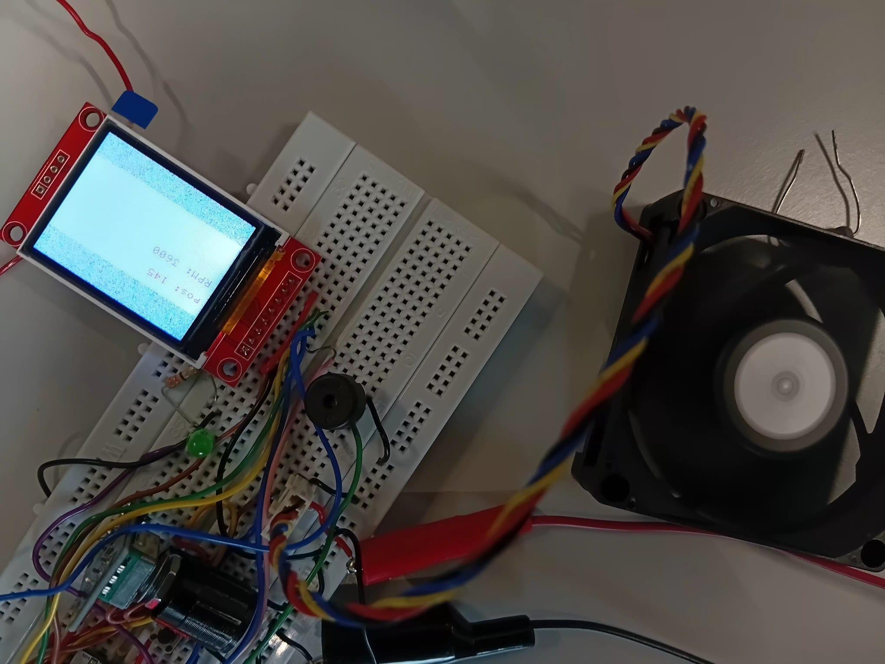
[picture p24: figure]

Figure 31: PC fan Assemble with LED OFF, Buzzer toggling and Screen . The result in Figure 31 shows the output speed signal from the PC fan with LED OFF, Fan ON

and at maximum and Screen indicating rotary position: 145 and speed 3600 RPM. Conclusion:

The Advanced PC Fan Speed Controller using the STM32L432KC microcontroller was successfully designed, implemented, and tested. The project achieved all objectives, including schematic design, software and hardware implementation, testing, debugging, and documentation. The system effectively controlled fan speed through PWM generation, monitored RPM using tachometer feedback, and provided real-time user interaction through

the LCD display and serial communication. Safety features such as LED indication and buzzer alerts operated correctly during over speed conditions. Experimental results confirmed accurate PWM control, reliable speed measurement, and stable system performance, demonstrating the effectiveness of the STM32-based embedded control system for PC fan

applications.

References:
[1] STMicroelectronics STM32L432KC Datasheet, (https://www.st.com/resource/en/datasheet/stm32l432kc.pdf?utm_source=chatgpt.com) “STM32L432KC Datasheet,” STMicroelectronics, Geneva, Switzerland, 2023. Accessed: May 8, 2026. [2] STM32L4 Series Reference Manual RM0394, “STM32L4x1 Advanced ARM®-based 32-bit

MCUs Reference Manual,” STMicroelectronics, Geneva, Switzerland, 2023. Accessed: May 8, 2026. [3] Omron Tactile Switches, “Tactile Switch Specifications,” Omron Electronics, Kyoto, Japan. Accessed: May 8, 2026. [4] Kingbright LED Products, “LED Component Datasheets,” Kingbright Electronic Co., Taipei, Taiwan. Accessed: May 8, 2026. [5] Vishay Resistors, “Resistor Products and Specifications,” Vishay Intertechnology, Malvern, PA, USA. Accessed: May 8, 2026. [6] Bourns Rotary Encoders, “Incremental Rotary Encoder Datasheets,” Bourns Inc., Riverside, CA, USA. Accessed: May 8, 2026. [7] ST7735 TFT LCD Controller Datasheet, “ST7735 TFT LCD Controller/Driver Datasheet,” Sitronix Technology Corp., Hsinchu, Taiwan. Accessed: May 8, 2026. [8] Murata Piezoelectric Sound Components, “Piezoelectric Sound Components,” Murata

Manufacturing Co., Kyoto, Japan. Accessed: May 8, 2026. [9] Intel 4-Wire PWM Controlled Fan Specification, (https://www.intel.com/content/dam/support/us/en/documents/intel-nuc/intel-4wire-pwm-fans-specs.pdf) “4-Wire Pulse Width Modulation (PWM)

Controlled Fans Specification,” Intel Corporation, Santa Clara, CA, USA, Sep. 2005. Accessed: May 8, 2026. [10] STMicroelectronics USART Application Note, “USART Communication Application Note,” STMicroelectronics, Geneva, Switzerland. Accessed: May 8, 2026. [11] SparkFun Breadboard Tutorial, “How to Use a Breadboard,” SparkFun Electronics, Boulder, CO, USA. Accessed: May 8, 2026. [12] Pololu Jumper Wires, “Jumper Wire Specifications,” Pololu Corporation, Las Vegas, NV, USA. Accessed: May 8, 2026. [13] Keysight Bench Power Supply Basics, “Fundamentals of DC Power Supplies,” Keysight

Technologies, Santa Rosa, CA, USA. Accessed: May 8, 2026.

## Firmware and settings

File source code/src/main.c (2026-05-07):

// ------------------------------------------------------------
// System: STM32L432 Fan Control with Encoder + Tach Feedback
//
// Functionality:
// - Rotary encoder (TIM2) sets PWM duty cycle (TIM16 on PA6)
// - Fan tach signal (PB4 interrupt) measures speed
// - Speed displayed via serial + SPI display
// - LED indicates maximum speed condition
// ------------------------------------------------------------
#include <stm32l432xx.h>
#include <stdint.h>
#include <math.h>

void setup(void);
void delay(volatile uint32_t dly);
void enablePullUp(GPIO_TypeDef *Port, uint32_t BitNumber);
void pinMode(GPIO_TypeDef *Port, uint32_t BitNumber, uint32_t Mode);
void initADC(void);
int readADC(int chan);
void initTimer2(void);
void setTimer2Duty(int duty);
void initClocks(void);
void delay_ms(unsigned dly);
void initEncoder(void);
void initBuzzerTimer(void);

// added from serial file
#include <eeng1030_lib.h>
#include <stdio.h>
#include  <errno.h>
#include  <sys/unistd.h> // STDOUT_FILENO, STDERR_FILENO

#include "display.h"


void initSerial(uint32_t baudrate);
void eputc(char c);

// define needed constants
#define pulse_per_rev 2

#define BEEP_SAMPLES 4790
int16_t audioBuffer[BEEP_SAMPLES * 2];
volatile uint8_t playing = 0;// 0 = buzzer off, 1 = buzzer on (controlled by TIM6)

int vin, speed_hz, speed_rpm;
volatile unsigned pulse_count, milliseconds;

// ------------------------------------------------------------
// TIM16 - PWM output for fan speed control on PA6
// ------------------------------------------------------------
void initTimer16()
{
    RCC->AHB2ENR |= (1 << 0);          // GPIOA clock on — must be before AFR access
    RCC->APB2ENR |= (1 << 17);         // TIM16 clock on

    // Manually configure PA6 as AF14 — do NOT use selectAlternateFunction
    GPIOA->AFR[0] &= ~(0xF << 24);     // clear PA6 AF bits (bits 27:24)
    GPIOA->AFR[0] |=  (14  << 24);     // set AF14

    GPIOA->MODER  &= ~(3u << 12);      // clear PA6 mode bits
    GPIOA->MODER  |=  (2u << 12);      // set alternate function mode

    // CHECK IMMEDIATELY AFTER WRITING
    printf("MODER inside initTimer16: %lu\r\n", (GPIOA->MODER >> 12) & 0x3);

    TIM16->CR1   = 0;
    TIM16->PSC   = 0;
    TIM16->ARR   = 3199;               // 80MHz / 3200 = 25kHz
    TIM16->CCMR1 = (0b110 << 4) | (1 << 3) | (1 << 2);
    TIM16->CCER  = (1 << 0);           // CC1E
    TIM16->CCR1  = 1600;               // 50% duty
    TIM16->BDTR  = (1 << 15);          // MOE
    TIM16->EGR  |= (1 << 0);
    TIM16->CR1   = (1 << 7) | (1 << 0);

    // CHECK AGAIN AT END OF FUNCTION
    printf("MODER end of initTimer16: %lu\r\n", (GPIOA->MODER >> 12) & 0x3);
}
// ------------------------------------------------------------
// TIM6 - Buzzer tone generator (toggles PB6 at 500Hz)
// ------------------------------------------------------------
void initBuzzerTimer(void)
{
    RCC->APB1ENR1 |= (1 << 4);   // enable TIM6 clock

    TIM6->CR1  = 0;
    TIM6->PSC  = 7999;            // 80MHz / 8000 = 10kHz
    TIM6->ARR  = 9;               // 10kHz / 10 = 1kHz toggle → 500Hz buzz tone
    TIM6->DIER = (1 << 0);        // enable update interrupt
    TIM6->EGR  = (1 << 0);        // generate update event
    TIM6->CR1  = (1 << 0);        // start timer

    NVIC->ISER[1] |= (1 << 22);   // TIM6 IRQ = 54, bit 22 of ISER[1]
}

int main()
{
    setup();
    SysTick->LOAD = 80000-1; // Systick clock = 80MHz. 80000000/80000=1000
	SysTick->CTRL = 7; // enable systick counter and its interrupts
	SysTick->VAL = 10; // start from a low number so we don't wait for ages for first interrupt

    initEncoder(); // TIM2 (input)
    init_display(); // SPI display
    initTimer16(); //TIM16 (PWM)
    initBuzzerTimer();      // TIM6 - buzzer tone generator

    delay_ms(2000);

    printf("MODER PA6: %lu\r\n",  (GPIOA->MODER >> 12) & 0x3);  // should be 2
    printf("AFR PA6:   %lu\r\n",  (GPIOA->AFR[0] >> 24) & 0xF); // should be 14
    printf("TIM16 CR1:  %lu\r\n", TIM16->CR1);   // should be 0x81
    printf("TIM16 CCER: %lu\r\n", TIM16->CCER);  // should be 0x1
    printf("TIM16 BDTR: %lu\r\n", TIM16->BDTR);  // should be 0x8000
    printf("TIM16 ARR:  %lu\r\n", TIM16->ARR);   // should be 3199
    printf("TIM16 CCR1: %lu\r\n", TIM16->CCR1);  // should be 1600
    
    while(1)
    {        
        vin = TIM2->CNT;

        TIM16->CCR1 = (vin * 3199) / 159;

        //uncomment
        uint32_t pulses;

        __disable_irq();
        pulses = pulse_count;

        pulse_count = 0;

        //uncomment
        __enable_irq();
    
        // evaluate speed 
        speed_hz = (pulses / pulse_per_rev);
        speed_rpm = (speed_hz * 450);

        // LED: ON when speed is safe (<=3500), OFF when too fast
        if (speed_rpm <= 3500)
        {
            GPIOB->ODR |= (1 << 5);  // turn LED on — normal speed
            playing = 0;             // buzzer off
        }
        else
        {
            GPIOB->ODR &= ~(1 << 5); // turn LED off — overspeed
            playing = 1;               // buzzer on via TIM6
        
        }

        // print fan speed 
        printf("ENC: %d, CCR1: %lu, RPM: %d,buzz: %lu\r\n", vin, TIM16->CCR1, speed_rpm,(GPIOB->ODR >> 6) & 1);

        // Clear text areas for display
        fillRectangle(0,10,160,20,RGBToWord(0,0,0));
        fillRectangle(0,30,160,20,RGBToWord(0,0,0));

        // Display values
        char buffer[50];

        sprintf(buffer, "pos: %3d", vin);
        printText(buffer, 5, 10, RGBToWord(255,255,0), 0);

        sprintf(buffer, "RPM: %4d", speed_rpm);
        printText(buffer, 5, 30, RGBToWord(0,255,0), 0);

        delay_ms(100);
    }
}

// ------------------------------------------------------------
// Setup
// ------------------------------------------------------------
void setup(void)
{
    initClocks();
    RCC->AHB2ENR |= (1 << 0) | (1 << 1); // turn on GPIOA and GPIOB

    pinMode(GPIOB,3,1); // PB3 digital output
    pinMode(GPIOB,4,0); // PB4 digital input (tachometer)
    
    pinMode(GPIOB, 5, 1); // PB5 output for LED

    pinMode(GPIOB, 6, 1); // PB6 as output for buzzer

    enablePullUp(GPIOB,4); // pull-up for tach input

    //to comment the below to initserial
    //pinMode(GPIOA,0,3);  // analog input
    
    pinMode(GPIOA,3,2);  // alternative function mode
    GPIOA->AFR[0] &= ~(3 << (2*3));    // Clear out old alternative function  bits
  
    GPIOA->AFR[0] |= 1 << (4*3);    // Select alternative function 1

    // serial communication 
    //initADC();
    initSerial(9600); //115200
    //initTimer2();

    // EXTI4 interrupt for tach pulse counting on PB4
    RCC->APB2ENR |= (1 << 0); // enable SYSCFG

    SYSCFG->EXTICR[1] &= ~(7 << 0); // clear perhaps previously set bits
    SYSCFG->EXTICR[1] |= (1 << 0);  // map EXTI2 interrupt to PB4
    
    EXTI->FTSR1 |= (1 << 4); // select falling edge trigger for PB4 input
    EXTI->IMR1 |= (1 << 4);  // enable PB4 interrupt
    
    NVIC->ISER[0] |= (1 << 10); // IRQ 10 maps to EXTI4
    __enable_irq();

}

void delay(volatile uint32_t dly)
{
    while(dly--);
}

void enablePullUp(GPIO_TypeDef *Port, uint32_t BitNumber)
{
	Port->PUPDR = Port->PUPDR &~(3u << BitNumber*2); // clear pull-up resistor bits
	Port->PUPDR = Port->PUPDR | (1u << BitNumber*2); // set pull-up bit
}
void pinMode(GPIO_TypeDef *Port, uint32_t BitNumber, uint32_t Mode)
{
	/*
        Modes : 00 = input
                01 = output
                10 = special function
                11 = analog mode
	*/
	uint32_t mode_value = Port->MODER;
	Mode = Mode << (2 * BitNumber);
	mode_value = mode_value & ~(3u << (BitNumber * 2));
	mode_value = mode_value | Mode;
	Port->MODER = mode_value;
}
// delete timer 2 completely  or replace with 

void initTimer2(void)
{
    RCC->APB1ENR1 |= (1 << 0); // enable Timer 2
    TIM2->CR1 = 0;
    TIM2->CCMR2 = (0b110 << 12) + (1 << 11)+(1 << 10);
    TIM2->CCER |= (1 << 12);
    TIM2->ARR = 2000-1;
    TIM2->CCR4 = 500;
    TIM2->EGR |= (1 << 0);
    TIM2->CR1 = (1 << 7);
    TIM2->CR1 |= (1 << 0);  
}

void initClocks()
{
	// Initialize the clock system to a higher speed.
	// At boot time, the clock is derived from the MSI clock 
	// which defaults to 4MHz.  Will set it to 80MHz
	// See chapter 6 of the reference manual (RM0393)
	    RCC->CR &= ~(1 << 24); // Make sure PLL is off

	    RCC->PLLCFGR = (1 << 25) + (1 << 24) + (1 << 22) + (1 << 21) + (1 << 17) + (80 << 8) + (1 << 0);	
	    RCC->CR |= (1 << 24); // Turn PLL on
	    while( (RCC->CR & (1 << 25))== 0); // Wait for PLL to be ready
	// configure flash for 4 wait states (required at 80MHz)
	    FLASH->ACR &= ~((1 << 2)+ (1 << 1) + (1 << 0));
	    FLASH->ACR |= (1 << 2); 
	    RCC->CFGR |= (1 << 1)+(1 << 0); // Select PLL as system clock
}

// added from serial communication file
void initSerial(uint32_t baudrate)
{
    RCC->AHB2ENR |= (1 << 0); // make sure GPIOA is turned on
    pinMode(GPIOA,2,2); // alternate function mode for PA2
    selectAlternateFunction(GPIOA,2,7); // AF7 = USART2 TX
    pinMode(GPIOA,15,2); 
    selectAlternateFunction(GPIOA,15,3);
    RCC->APB1ENR1 |= (1 << 17); // turn on USART2

	const uint32_t CLOCK_SPEED=80000000;    
	uint32_t BaudRateDivisor;
	
	BaudRateDivisor = CLOCK_SPEED/baudrate;	
	USART2->CR1 = 0;
	USART2->CR2 = 0;
	USART2->CR3 = (1 << 12); // disable over-run errors
	USART2->BRR = BaudRateDivisor;
	USART2->CR1 =  (1 << 3);  // enable the transmitter and receiver
    USART2->CR1 |=  (1 << 2);  // enable the transmitter and receiver
	USART2->CR1 |= (1 << 0);
}
int _write(int file, char *data, int len)
{
    if ((file != STDOUT_FILENO) && (file != STDERR_FILENO))
    {
        errno = EBADF;
        return -1;
    }
    while(len--)
    {
        eputc(*data);    
        data++;
    }    
    return 0;
}
void eputc(char c)
{
    while( (USART2->ISR & (1 << 6))==0); // wait for ongoing transmission to finish
    USART2->TDR=c;
}       

void EXTI4_IRQHandler()
{
    //PIOB->BSRR = (1 << 3); // set PB3 to turn on LED 
    //GPIOB->IDR |= (1 << 4);
    EXTI->PR1 = (1 << 4);   // clear interrupt pending flag
    pulse_count++; //counting the pulse
    
}

// ------------------------------------------------------------
// TIM6 ISR - toggles PB6 to generate buzzer tone
// ------------------------------------------------------------
void TIM6_DAC_IRQHandler(void)
{
    TIM6->SR &= ~(1 << 0);             // clear update interrupt flag

    if (playing)
    {
        GPIOB->ODR ^= (1 << 6);        // toggle PB6 → 500Hz tone on buzzer
    }
    else
    {
        GPIOB->ODR &= ~(1 << 6);       // ensure buzzer pin is LOW when off
    }
}


void SysTick_Handler(void)
{    
   milliseconds++;
}
void delay_ms(unsigned dly){
    unsigned end = milliseconds + dly;
    while(milliseconds != end);
}
// I/O List for Encoder:
// PA0 : TIM2_CH1 (Alternative function 1) : Clock pin on encoder
// PB3 : TIM2_CH2 (Alternative function 1) : DT pin on encoder (quadrature type input)
// PB4 : GPIOA - SW input from encoder (maybe)
void initEncoder()
{
    RCC->AHB2ENR |= (1 << 0) | (1 << 1); // make sure GPIOA,B are turned on   
    pinMode(GPIOA,0,2);
    selectAlternateFunction(GPIOA,0,1);
    pinMode(GPIOB,3,2);
    selectAlternateFunction(GPIOB,3,1);
    //pinMode(GPIOB,4,0);
    RCC->APB1ENR1 |= (1 << 0); // enable Timer 2
    
    TIM2->CR1 = 0;
    TIM2->CNT = 0;

    TIM2->ARR = 159; // full range encoder count

    // Encoder mode 3 (TI1 + TI2)
    TIM2->SMCR = 3;

    // TI1 and TI2 as inputs
    TIM2->CCMR1 = 0;
    TIM2->CCMR1 |= (1 << 0);  // CC1S = input
    TIM2->CCMR1 |= (1 << 8);  // CC2S = input

    TIM2->CCER = 0;

    TIM2->CR1 |= 1;

}

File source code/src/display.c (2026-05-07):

#include <display.h>
#include <stdint.h>
#include <stm32l432xx.h>
#include "eeng1030_lib.h"
#include "font5x7.h"
#include "spi.h"
#include "eeng1030_lib.h"   // provides pinMode
//#include "main.h"            // or wherever delay_ms is declared
#define SCREEN_HEIGHT 80
#define SCREEN_WIDTH 160
/*	I/O List
		PA7  : SPI1 MOSI : Alternative function 5
        PA6  : Reset : GPIO Output
        PA5  : D/C : GPIO Output
		PA4  : CS : GPIO Output
		PA1  : SPI1 SCLK : Alternative function 5    
*/
static void CSLow(void);
static void CSHigh(void);
static void DCLow(void);
static void DCHigh(void);
static void ResetHigh(void);
static void ResetLow(void);
static void command(uint8_t cmd);
static void data(uint8_t data);
void clear(void);
static uint32_t mystrlen(const char *s);
static void drawLineLowSlope(uint16_t x0, uint16_t y0, uint16_t x1,uint16_t y1, uint16_t Colour);
static void drawLineHighSlope(uint16_t x0, uint16_t y0, uint16_t x1,uint16_t y1, uint16_t Colour);
static int iabs(int x);
static void openAperture(uint16_t x1, uint16_t y1, uint16_t x2, uint16_t y2);
void putPixel(uint16_t x, uint16_t y, uint16_t colour);
void putImage(uint16_t x, uint16_t y, uint16_t width, uint16_t height, const uint16_t *Image, int hOrientation, int vOrientation);
void drawLine(uint16_t x0, uint16_t y0, uint16_t x1, uint16_t y1, uint16_t Colour);
void fillRectangle(uint16_t x,uint16_t y,uint16_t width, uint16_t height, uint16_t colour);
void init_display()
{
    RCC->AHB2ENR |= (1 << 1); // enable GPIOB clock
    
    // Change this:
    //pinMode(GPIOA,6,1);
    // To this:
    pinMode(GPIOB,0,1);
    
    pinMode(GPIOA,5,1);
    pinMode(GPIOA,4,1);
    initSPI(SPI1);
    // Lots of CS toggling here seems to have made the boot up more reliable
	ResetHigh();	
	delay_ms(10);
	ResetLow();
	delay_ms(200);
	ResetHigh();
	CSHigh();
	delay_ms(200);
	CSLow();
	delay_ms(20);
	command(0x01); // software reset
	delay_ms(100);
	CSHigh();
	delay_ms(1);
	CSLow();
	delay_ms(1);
	command(0x11); // exit sleep
	delay_ms(120);
	// set frame rate
	CSHigh();
	delay_ms(1);
	CSLow();
	delay_ms(1);
	command(0xb1);
	data(0x05);
	data(0x3c);
	data(0x3c);
	CSHigh();
	delay_ms(1);
	CSLow();
	delay_ms(1);
	command(0xb2);
	data(0x05);
	data(0x3c);
	data(0x3c);
	CSHigh();
	delay_ms(1);
	CSLow();
	delay_ms(1);
	command(0xb3);
	data(0x05);
	data(0x3c);
	data(0x3c);	
	data(0x05);
	data(0x3c);
	data(0x3c);
	CSHigh();
	delay_ms(1);
	CSLow();
	delay_ms(1);
	command(0xb4); // dot invert
	data(0x03);
	CSHigh();
	delay_ms(1);			
	CSHigh();
	delay_ms(1);
	CSLow();
	delay_ms(1);
	command(0x36);// Set pixel and RGB order
	data(0x60); 	
	CSHigh();
	delay_ms(1);
	CSLow();
	delay_ms(1);		
	CSHigh();
	delay_ms(1);
	CSLow();
	delay_ms(1);
	command(0x3a);// Set colour mode        
	data(0x5); 	// 16 bits per pixel
	CSHigh();
	delay_ms(1);
	CSLow();
	delay_ms(1);
	command(0x29);    // display on
	delay_ms(100);
	CSHigh();
	delay_ms(1);
	CSLow();
	delay_ms(1);
    command(0x21);
    delay_ms(1);
    command(0x2c);   // put display in to write mode
	fillRectangle(0,0,SCREEN_WIDTH, SCREEN_HEIGHT, 0x00);  // black out the screen

}
static void CSHigh(void)
{
    GPIOA->ODR |= (1 << 4);
}
static void CSLow(void)
{
    GPIOA->ODR &= ~(1 << 4);
}
static void DCHigh(void)
{
    GPIOA->ODR |= (1 << 5);
}
static void DCLow(void)
{
    GPIOA->ODR &= ~(1 << 5);
}
static void ResetHigh(void)
{
    // Change this:
    //GPIOA->ODR |= (1 << 6);
    // To this:
    GPIOB->ODR |= (1 << 0);
}
static void ResetLow(void)
{
    // Change this:
    //GPIOA->ODR &= ~(1 << 6);
    // To this:
    GPIOB->ODR &= ~(1 << 0);
}

static void command(uint8_t cmd)
{
    DCLow();
	transferSPI8(SPI1,cmd);
}
static void data(uint8_t data)
{
    DCHigh();
	transferSPI8(SPI1,data);
}

void openAperture(uint16_t x1, uint16_t y1, uint16_t x2, uint16_t y2)
{
    // open up an area for drawing on the display  
    x1 = x1 +1;
    x2 = x2+ 1;  
    y1 = y1+26;
    y2 = y2+26;
	command(0x2A); // Set X limits    	
    data(x1>>8);
    data(x1&0xff);        
    data(x2>>8);
    data(x2&0xff);
    
    command(0x2B);// Set Y limits
    data(y1>>8);
    data(y1&0xff);        
    data(y2>>8);
    data(y2&0xff);    
        
    command(0x2c); // put display in to data write mode
	
}
void fillRectangle(uint16_t x,uint16_t y,uint16_t width, uint16_t height, uint16_t colour)
{
	uint32_t pixelcount = height * width;
	openAperture(x, y, x + width - 1, y + height - 1);
	DCHigh();
	while(pixelcount--) 
	{
		transferSPI16(SPI1,colour);
	}	
}
void putPixel(uint16_t x, uint16_t y, uint16_t colour)
{
	openAperture(x, y, x + 1, y + 1);	
	DCHigh();
	transferSPI16(SPI1,colour);
}
void putImage(uint16_t x, uint16_t y, uint16_t width, uint16_t height, const uint16_t *Image, int hOrientation, int vOrientation)
{
    uint16_t Colour;
	  uint32_t offset = 0;
    openAperture(x, y, x + width - 1, y + height - 1);
    DCHigh();
	  if (hOrientation == 0)
		{
			if (vOrientation == 0)
			{
				for (y = 0; y < height; y++)
				{
						offset=y*width;
						for (x = 0; x < width; x++)
						{
								Colour = Image[offset+x];
								transferSPI16(SPI1,Colour);
						}
				}
			}
			else
			{
				for (y = 0; y < height; y++)
				{
						offset=(height-(y+1))*width;
						for (x = 0; x < width; x++)
						{
								Colour = Image[offset+x];
								transferSPI16(SPI1,Colour);
						}
				}
			}
		}
		else
		{
			if (vOrientation == 0)
			{
				for (y = 0; y < height; y++)
				{
						offset=y*width;
						for (x = 0; x < width; x++)
						{
								Colour = Image[offset+(width-x-1)];
								transferSPI16(SPI1,Colour);
						}
				}
			}
			else
			{
				for (y = 0; y < height; y++)
				{
						offset=(height-(y+1))*width;
						for (x = 0; x < width; x++)
						{
								Colour = Image[offset+(width-x-1)];
								transferSPI16(SPI1,Colour);
						}
				}
			}
		}
}
void drawLine(uint16_t x0, uint16_t y0, uint16_t x1, uint16_t y1, uint16_t Colour)
{
	// Reference : https://en.wikipedia.org/wiki/Bresenham%27s_line_algorithm    
    if ( iabs(y1 - y0) < iabs(x1 - x0) )
    {
        if (x0 > x1)
        {
            drawLineLowSlope(x1, y1, x0, y0, Colour);
        }
        else
        {
            drawLineLowSlope(x0, y0, x1, y1, Colour);
        }
    }
    else
    {
        if (y0 > y1) 
        {
            drawLineHighSlope(x1, y1, x0, y0, Colour);
        }
        else
        {
            drawLineHighSlope(x0, y0, x1, y1, Colour);
        }
        
    }    
}
int iabs(int x) // simple integer version of abs for use by graphics functions        
{
	if (x < 0)
		x = -x;
	return x;
}
void drawRectangle(uint16_t x, uint16_t y, uint16_t w, uint16_t h, uint16_t Colour)
{
	drawLine(x,y,x+w,y,Colour);
  drawLine(x,y,x,y+h,Colour);
  drawLine(x+w,y,x+w,y+h,Colour);
  drawLine(x,y+h,x+w,y+h,Colour);
}
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

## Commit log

2026-05-07 initil commit
    [embedded_project.kicad_pcb, embedded_project_design.kicad_sch]
2026-05-08 t push origin main
    [embedded_project_design.kicad_sch]
